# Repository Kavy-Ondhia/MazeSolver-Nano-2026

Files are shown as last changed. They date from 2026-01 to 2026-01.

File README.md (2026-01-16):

<h1 align="center">MazeSolver-Nano-2026 🏎️💨</h1>

A high-performance line-following and maze-solving robot built on the Arduino Nano platform. This project utilizes PID control and magnetic encoders for precision navigation.




<div align="center">
  <table style="width:100%; border-collapse: collapse; border: none; table-layout: fixed;">
    <tr>
      <td rowspan="2" style="width: 60%; border: none; padding: 2px;">
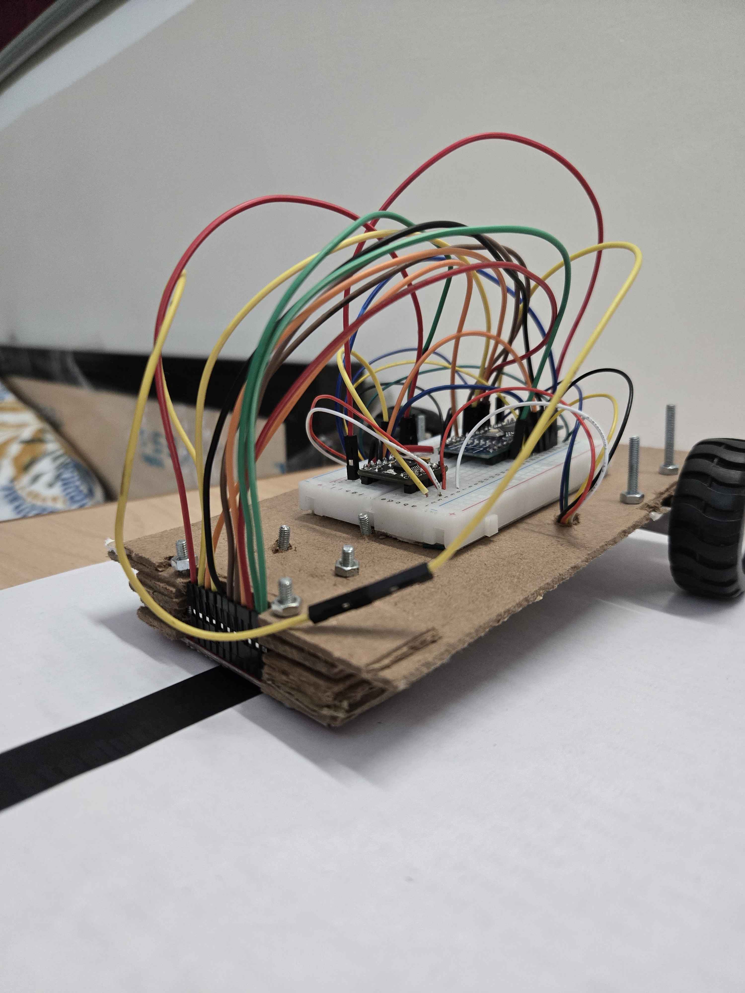
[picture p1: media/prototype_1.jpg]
Prototype Side View
        
      </td>
      <td style="width: 40%; border: none; padding: 2px;">
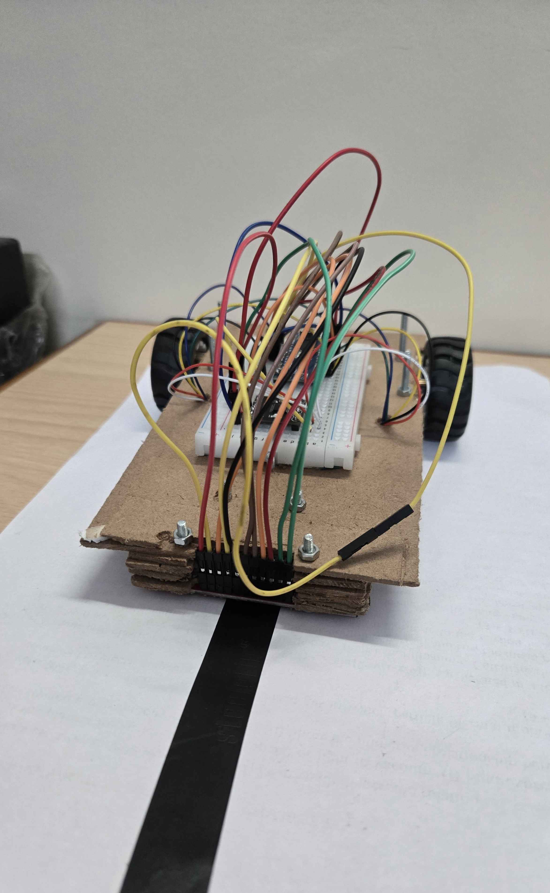
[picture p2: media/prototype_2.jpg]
Prototype Front View
        
      </td>
    </tr>
    <tr>
      <td style="border: none; padding: 2px;">
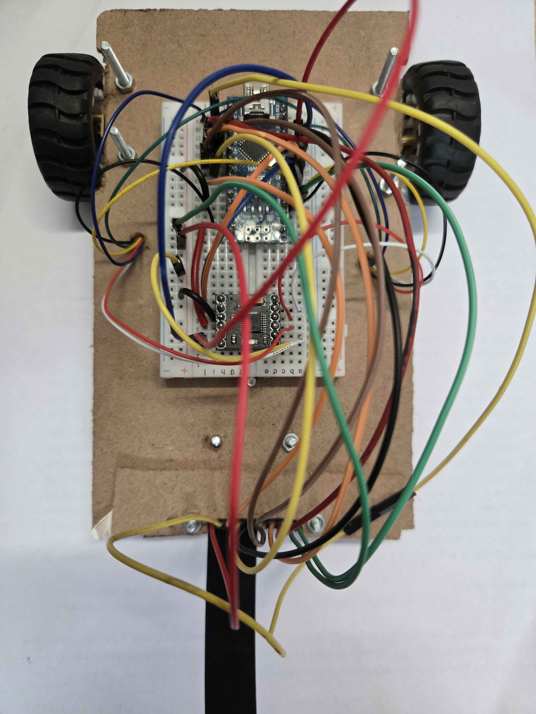
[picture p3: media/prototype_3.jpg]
Prototype Top View
        
      </td>
    </tr>
  </table>
</div>

## 🛠 Prototyping & PCB Manufacturing Phase
The project has moved from theoretical design to **active hardware-in-the-loop (HIL) testing**. I am currently validating a breadboard prototype to finalize signal routing and power stability for the custom PCB fabrication.

### **Current Progress:**
* **Prototype Controller:** Arduino Nano (ATmega328P) using a logic-stable common ground architecture.
* **Dual Motor Drive:** Integrated the **DRV8833 Dual H-Bridge** for the prototype phase, utilizing PWM-direct control to manage motor velocity and direction.
* **Sensor Integration:** Successfully calibrated a **QTR-8RC 8-channel array**. Pin mapping has been optimized (A0–A5, D7, D13) to prevent conflicts with motor PWM timers.
* **Precise Navigation:** Magnetic encoders are mapped to **Hardware Interrupt pins (D2, D3)** to ensure zero-loss pulse counting for PID speed control and distance tracking.

### **PCB Design Priorities:**
* **Signal Integrity:** Separating high-current motor traces from sensitive Encoder and Sensor signal lines to reduce Electromagnetic Interference (EMI).
* **Power Rail Optimization:** Implementing a **Buck Converter** to efficiently step down LiPo battery voltage for the logic circuit, significantly reducing heat compared to linear regulators.
* **Modular Footprint:** The PCB layout is being designed with a modular header to support both **DRV8833** and **TB6612FNG** driver footprints for testing flexibility.

## 👥 Development Team
* **Kavy Ondhia** ([@Kavy-Ondhia](https://github.com/Kavy-Ondhia))  
  *Lead Engineer — Firmware Architecture, Logic, & Hardware V2 (KiCad)*
  
* **Karunya Jajoo** ([@karunya-jajoo](https://github.com/karunya-jajoo))  
  *Contributor — Initial Hardware Concept & V1 Schematic*

## 🛠 Hardware Specifications

| Component | Purpose | Datasheet/Reference |
| :--- | :--- | :--- |
| **Arduino Nano** | Main Controller | [Official Manual](https://docs.arduino.cc/resources/datasheets/A000005-datasheet.pdf) |
| **TB6612FNG** | Motor Driver | [Toshiba Datasheet](https://www.sparkfun.com/datasheets/Robotics/TB6612FNG.pdf) |
| **N20 Motors** | 6V 200RPM w/ Encoders | [Technical Specs](https://www.handsontec.com/dataspecs/motor/N20-Motor.pdf) |
| **QTR-8RC** | IR Sensor Array | [Pololu Documentation](https://www.pololu.com/docs/0J12) |
| **SSD1306 OLED** | Debugging Display | [Adafruit Datasheet](https://cdn-shop.adafruit.com/datasheets/SSD1306.pdf) |
| **HC-05** | Bluetooth Module | [HC-05 Datasheet](https://components101.com/sites/default/files/component_datasheet/HC-05-Datasheet.pdf) |
| **LM2596 Buck** | 5V Regulation | [TI Datasheet](https://www.ti.com/lit/ds/symlink/lm2596.pdf) |

## 🔌 Proposed Pin Mapping (Nano)
*This table serves as the "contract" for the schematic design.*

| Standard Pin | KiCad Symbol Label | Component | Function | Status vs. Old |
| :--- | :--- | :--- | :--- | :--- |
| **D2** | D2 (Right Pin 11) | Encoder Left | Interrupt A (Phase A) | UNCHANGED |
| **D11** | D11 (Right Pin 2) | Encoder Left | Phase B (Dir Tracking) | UNCHANGED |
| **D3** | D3 (Right Pin 10) | Encoder Right | Interrupt B (Phase A) | UNCHANGED |
| **D12** | D12 (Right Pin 1) | Encoder Right | Phase B (Dir Tracking) | UNCHANGED |
| **D4** | D4 (Right Pin 9) | TB6612 (BIN1) | Right Motor Dir | UNCHANGED |
| **D5** | D5 (Right Pin 8) | TB6612 (BIN2) | Right Motor Dir | UNCHANGED |
| **D7** | D7 (Right Pin 6) | TB6612 (AIN1) | Left Motor Dir | UNCHANGED |
| **D8** | D8 (Right Pin 5) | TB6612 (AIN2) | Left Motor Dir | UNCHANGED |
| **D9** | D9 (Right Pin 4) | TB6612 (PWMA) | Left Motor Speed (PWM) | UNCHANGED |
| **D10** | D10 (Right Pin 3) | TB6612 (PWMB) | Right Motor Speed (PWM) | UNCHANGED |
| **A0** | D14 (Left Pin 4) | QTR-8RC Pin 1 | IR Reflectance | UNCHANGED |
| **A1** | D15 (Left Pin 5) | QTR-8RC Pin 2 | IR Reflectance | UNCHANGED |
| **A2** | D16 (Left Pin 6) | QTR-8RC Pin 3 | IR Reflectance | UNCHANGED |
| **A3** | D17 (Left Pin 7) | QTR-8RC Pin 4 | IR Reflectance | UNCHANGED |
| **D6** | D6 (Right Pin 7) | QTR-8RC Pin 5 | IR Reflectance | UNCHANGED |
| **A4** | D18 (Left Pin 8) | QTR-8RC Pin 6 | IR Reflectance | **MOVED** (From D13) |
| **A5** | D19 (Left Pin 9) | QTR-8RC Pin 7 | IR Reflectance | **MOVED** (From A6) |
| **D13** | D13 (Left Pin 1) | QTR-8RC Pin 8 | IR Reflectance | **MOVED** (From A7) |
| **D0** | D0 (RX) | NOT USED | Leave Empty for Uploads | **REMOVED** (Finish LED) |
| **A6 / A7** | A6 / A7 | NOT USED | Hardware Input Only | **VOID** |

### ⚠️ Critical Hardware Notes
* **A6/A7 Pins:** These pins on the Nano are **Analog Input Only**. They cannot be used for the QTR-8RC or Motor Standby because they cannot function as Digital Outputs.
* **QTR-8RC Version:** This project uses the **RC (Digital)** version of the sensor. Pins are toggled as outputs to charge the onboard capacitor, then read as inputs to measure discharge time.
* **USB Uploading:** Digital Pin **D0 (RX)** is left disconnected to prevent serial communication conflicts during code uploading.

## 🛠 Hardware Design

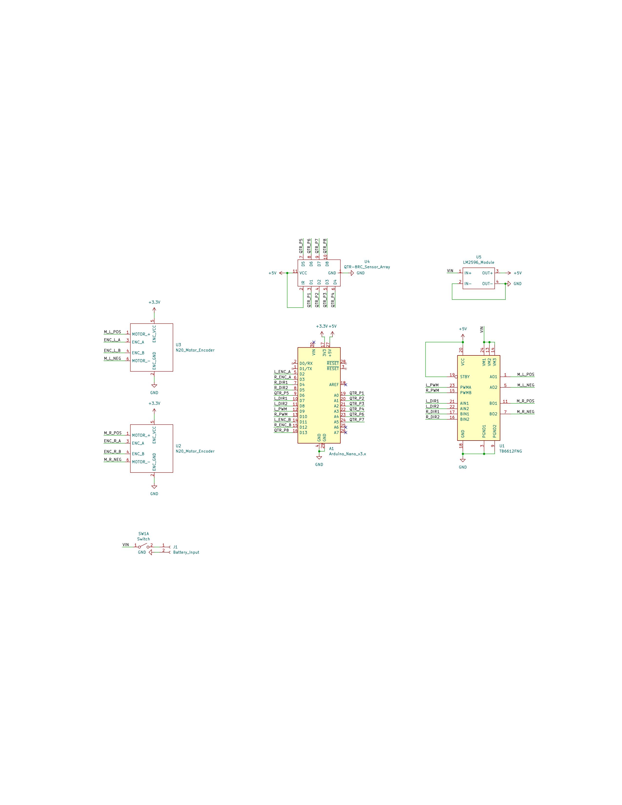
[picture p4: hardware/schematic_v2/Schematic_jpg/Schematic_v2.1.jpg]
Robot Schematic

[Download PDF Version](hardware/schematic_v2/Schematic_pdf/Schematic_v2.1.pdf)

## 🧠 Software Logic & Path Optimization

The robot's intelligence is divided into three layers: **Perception**, **Control**, and **Strategy**.

### 1. Perception & Control (PID)
* **The Error:** Using the QTR-8RC, we calculate the robot's position relative to the center (3500). 
    * $Error = 3500 - \text{Current Reading}$
* **PID Math:** We use Proportional (Muscle) and Derivative (Brakes) logic to calculate correction.
    * `Correction = (Kp * error) + (Kd * (error - lastError))`
    * `LeftSpeed = Base + Correction` | `RightSpeed = Base - Correction`

### 2. The Discovery Phase (Dry Run)
The robot uses a **Preferential Wall-Following Rule** (Straight > Left > Right). 
* **The Log:** Every move is recorded in a memory array.
* **Encoder Mapping:** Encoders track distance in millimeters to ensure precise turns and junction detection.

### 3. Path Optimization (The "Aha!" Moment)
The robot simplifies its recorded path by removing dead ends (represented as 'B' for Back).
* **Logic:** `Left -> Back -> Left` is simplified to `Straight`.
* **Optimization Example:** `L -> B -> L` becomes `S`. This "shrinks" the journey for the final run.

### 4. Advanced Mapping & Exploration
To cover the entire map, the robot utilizes a coordinate-based Node system:
```cpp
struct Node {
  long x;           // X coordinate from encoders
  long y;           // Y coordinate from encoders
  bool visited[3];  // [Left, Straight, Right]
  int parentNode;   // Back-tracking reference
};
```

## 📸 Component Gallery
<p align="center">
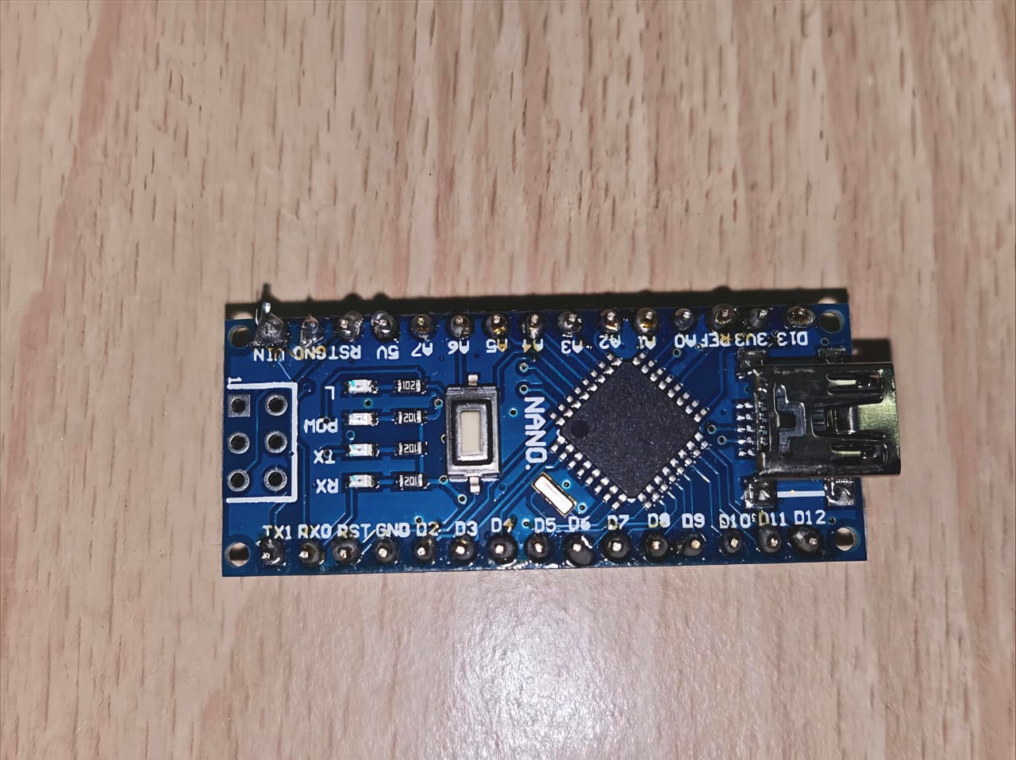
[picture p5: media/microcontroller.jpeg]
  
</p>
<p align="center">
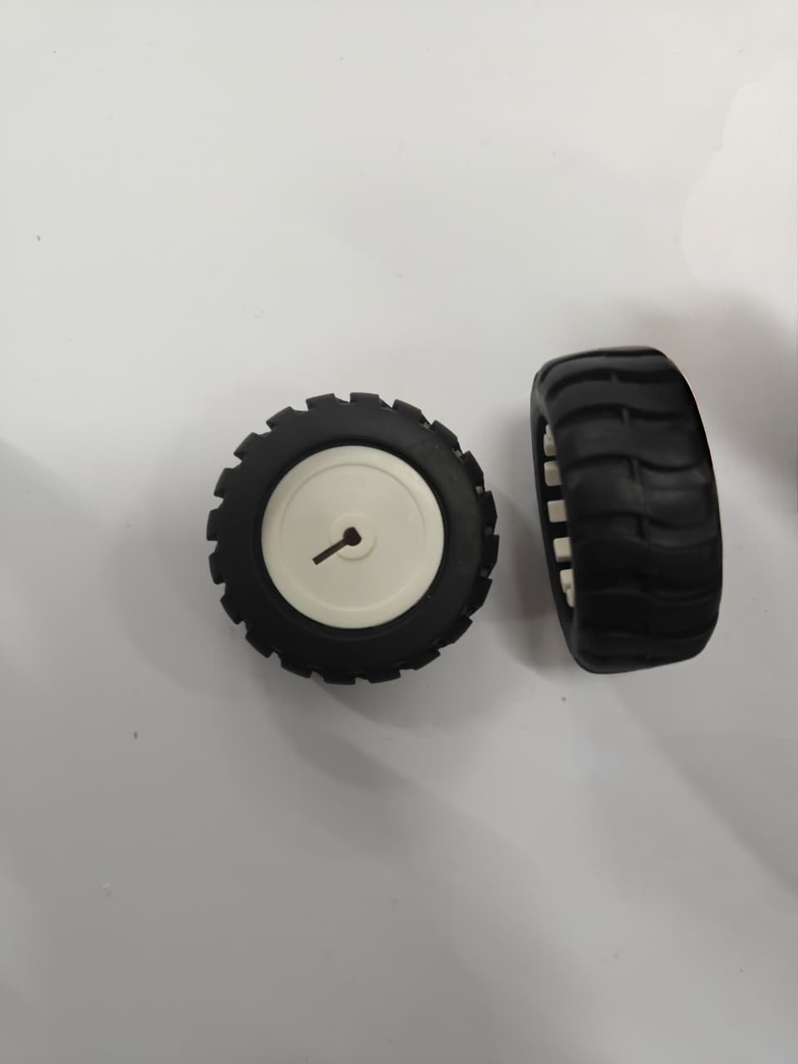
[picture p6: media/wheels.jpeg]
  
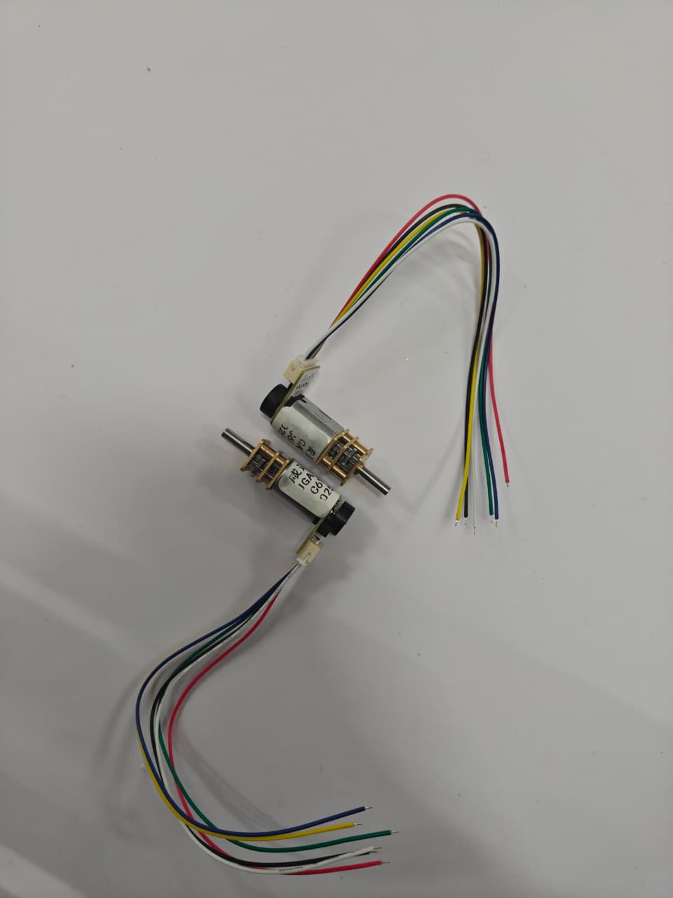
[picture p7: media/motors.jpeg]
  
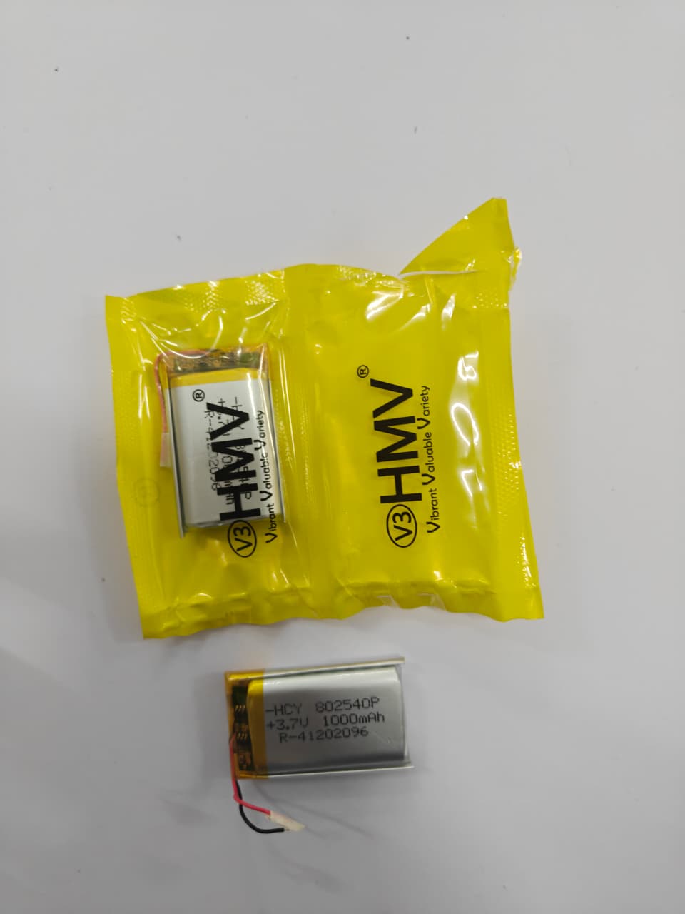
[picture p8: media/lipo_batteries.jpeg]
  
</p>
<p align="center">
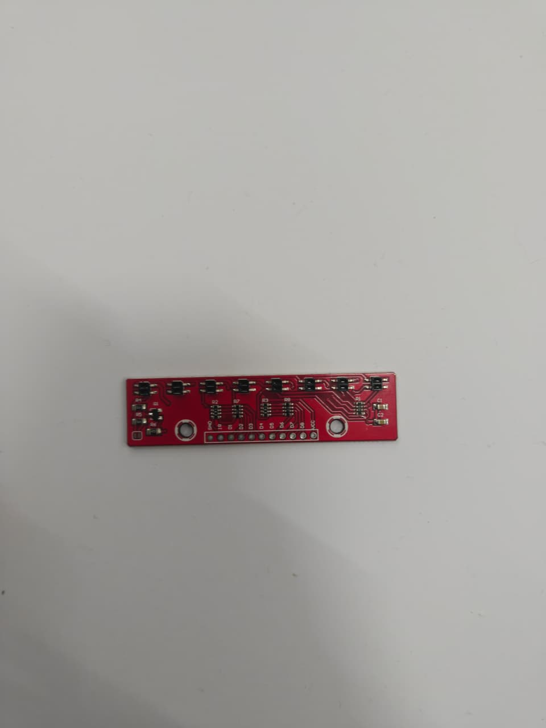
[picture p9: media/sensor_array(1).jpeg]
  
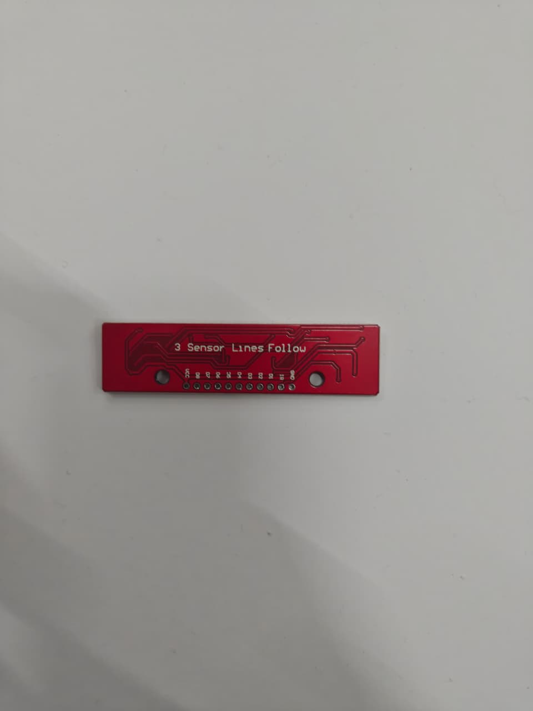
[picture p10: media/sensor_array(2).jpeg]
  
</p>

## 📂 Project Structure
* `/src`: Final Arduino (.ino) and configuration (.h) files.
* `/hardware`: Schematic diagrams and PCB layouts (In Progress).
* `/media`: Component photos and project progress shots.

---
*Created by [Kavy Ondhia](https://github.com/Kavy-Ondhia)*

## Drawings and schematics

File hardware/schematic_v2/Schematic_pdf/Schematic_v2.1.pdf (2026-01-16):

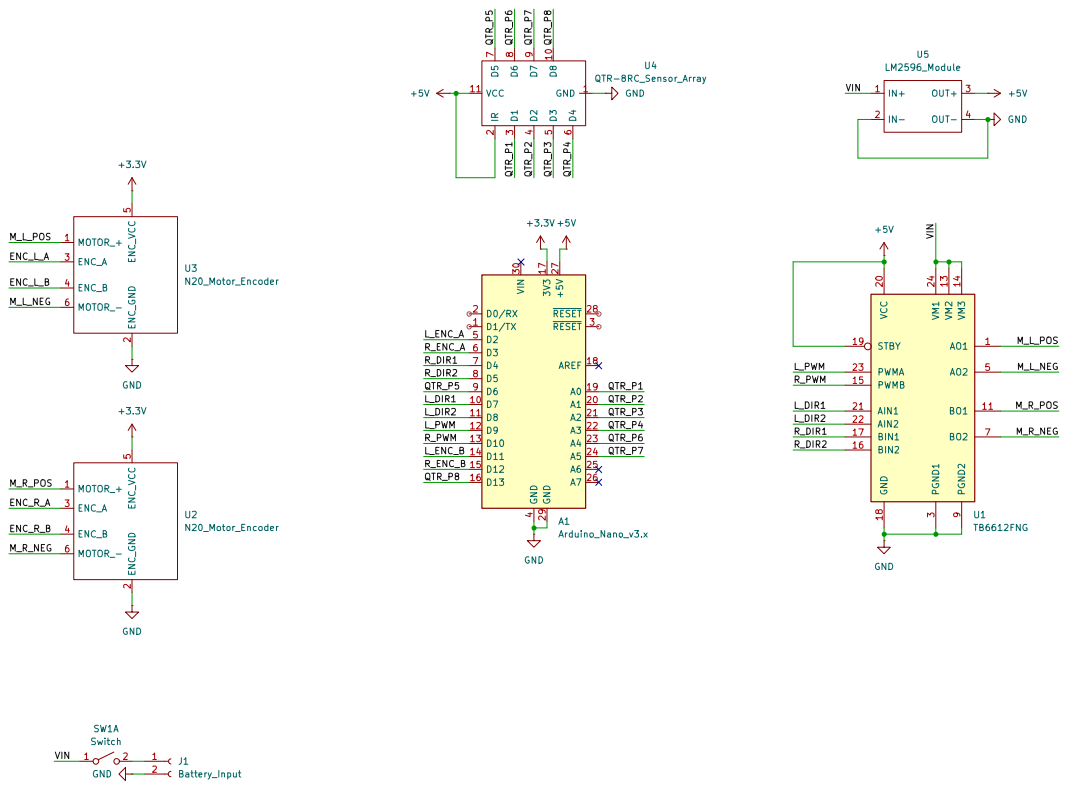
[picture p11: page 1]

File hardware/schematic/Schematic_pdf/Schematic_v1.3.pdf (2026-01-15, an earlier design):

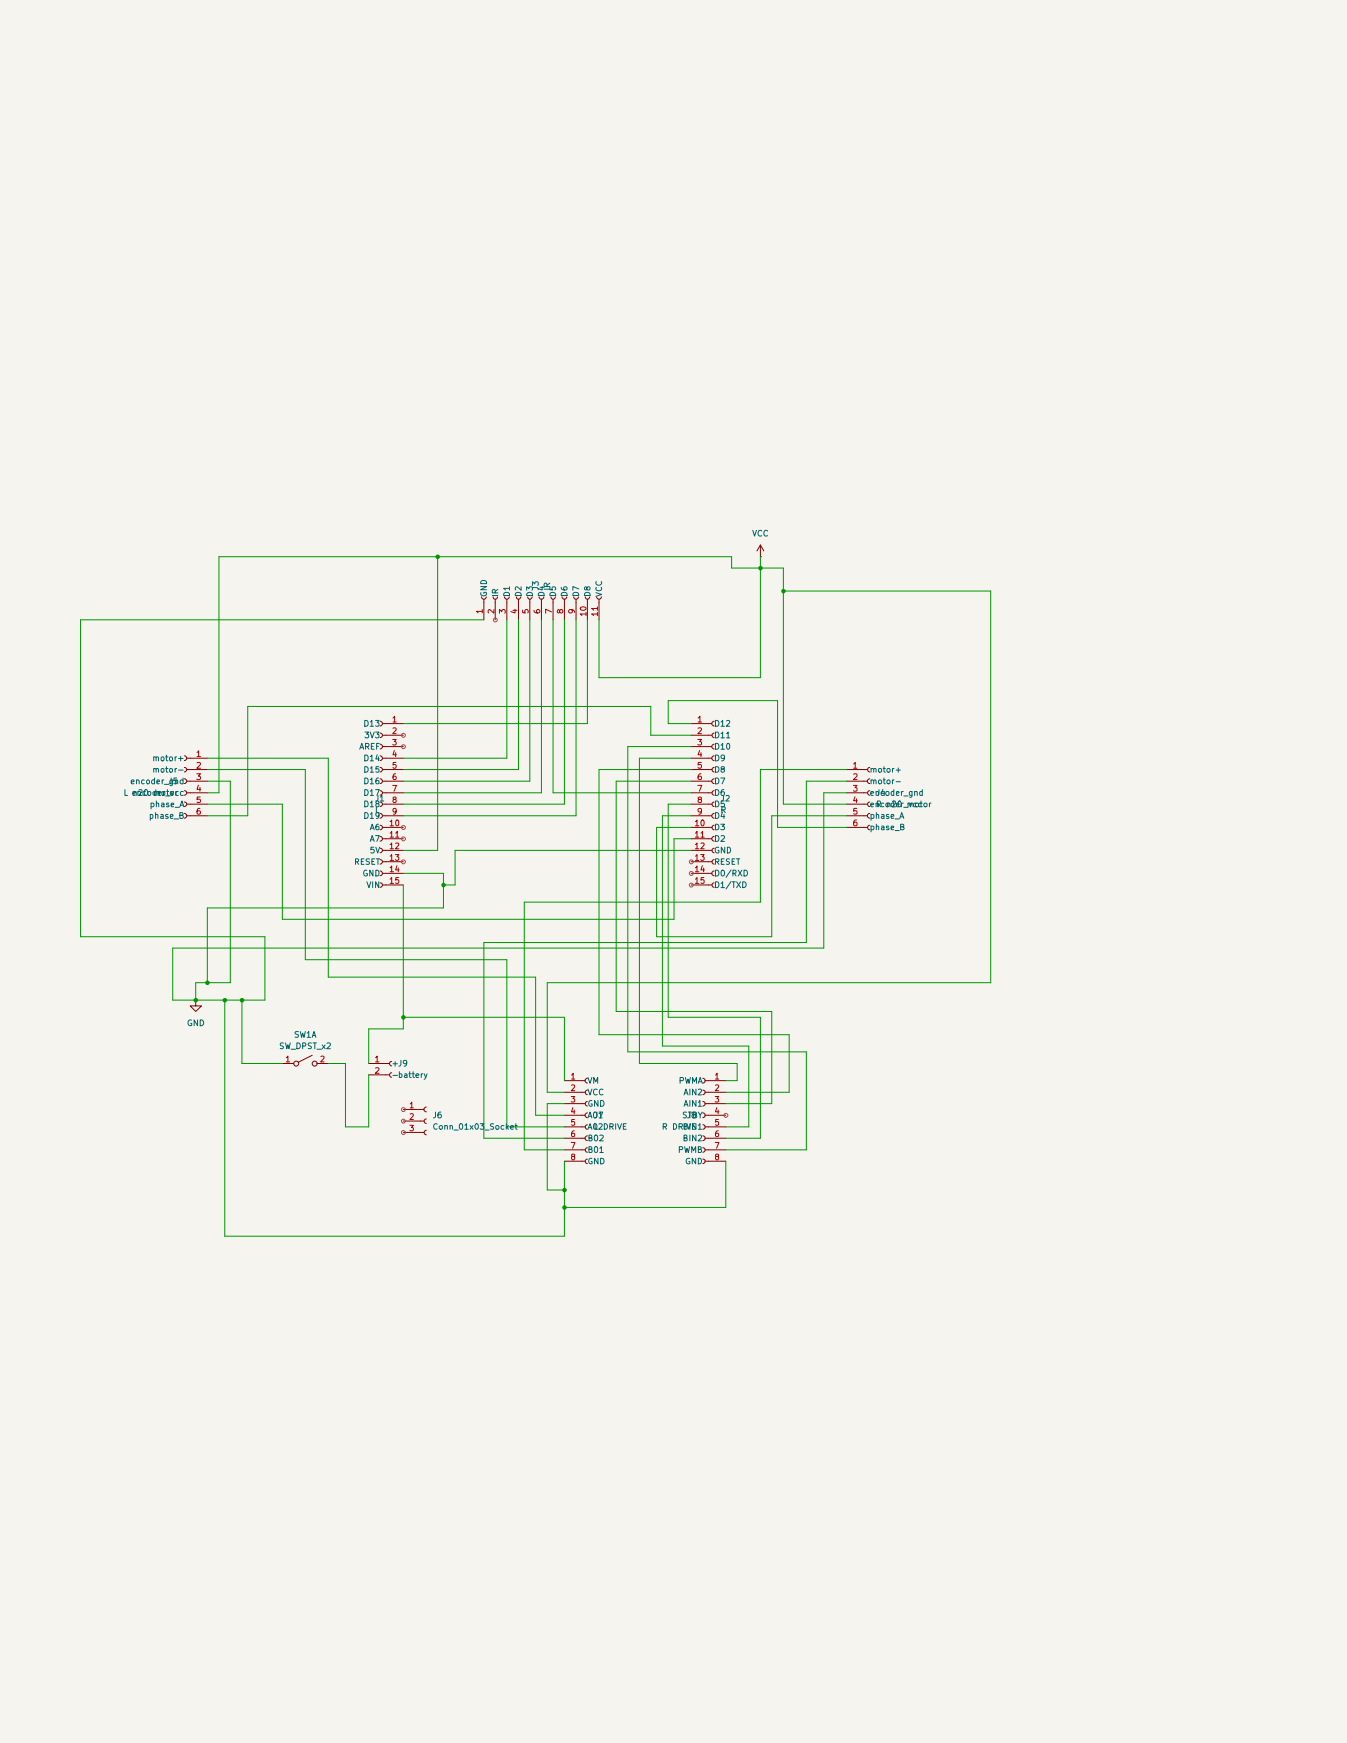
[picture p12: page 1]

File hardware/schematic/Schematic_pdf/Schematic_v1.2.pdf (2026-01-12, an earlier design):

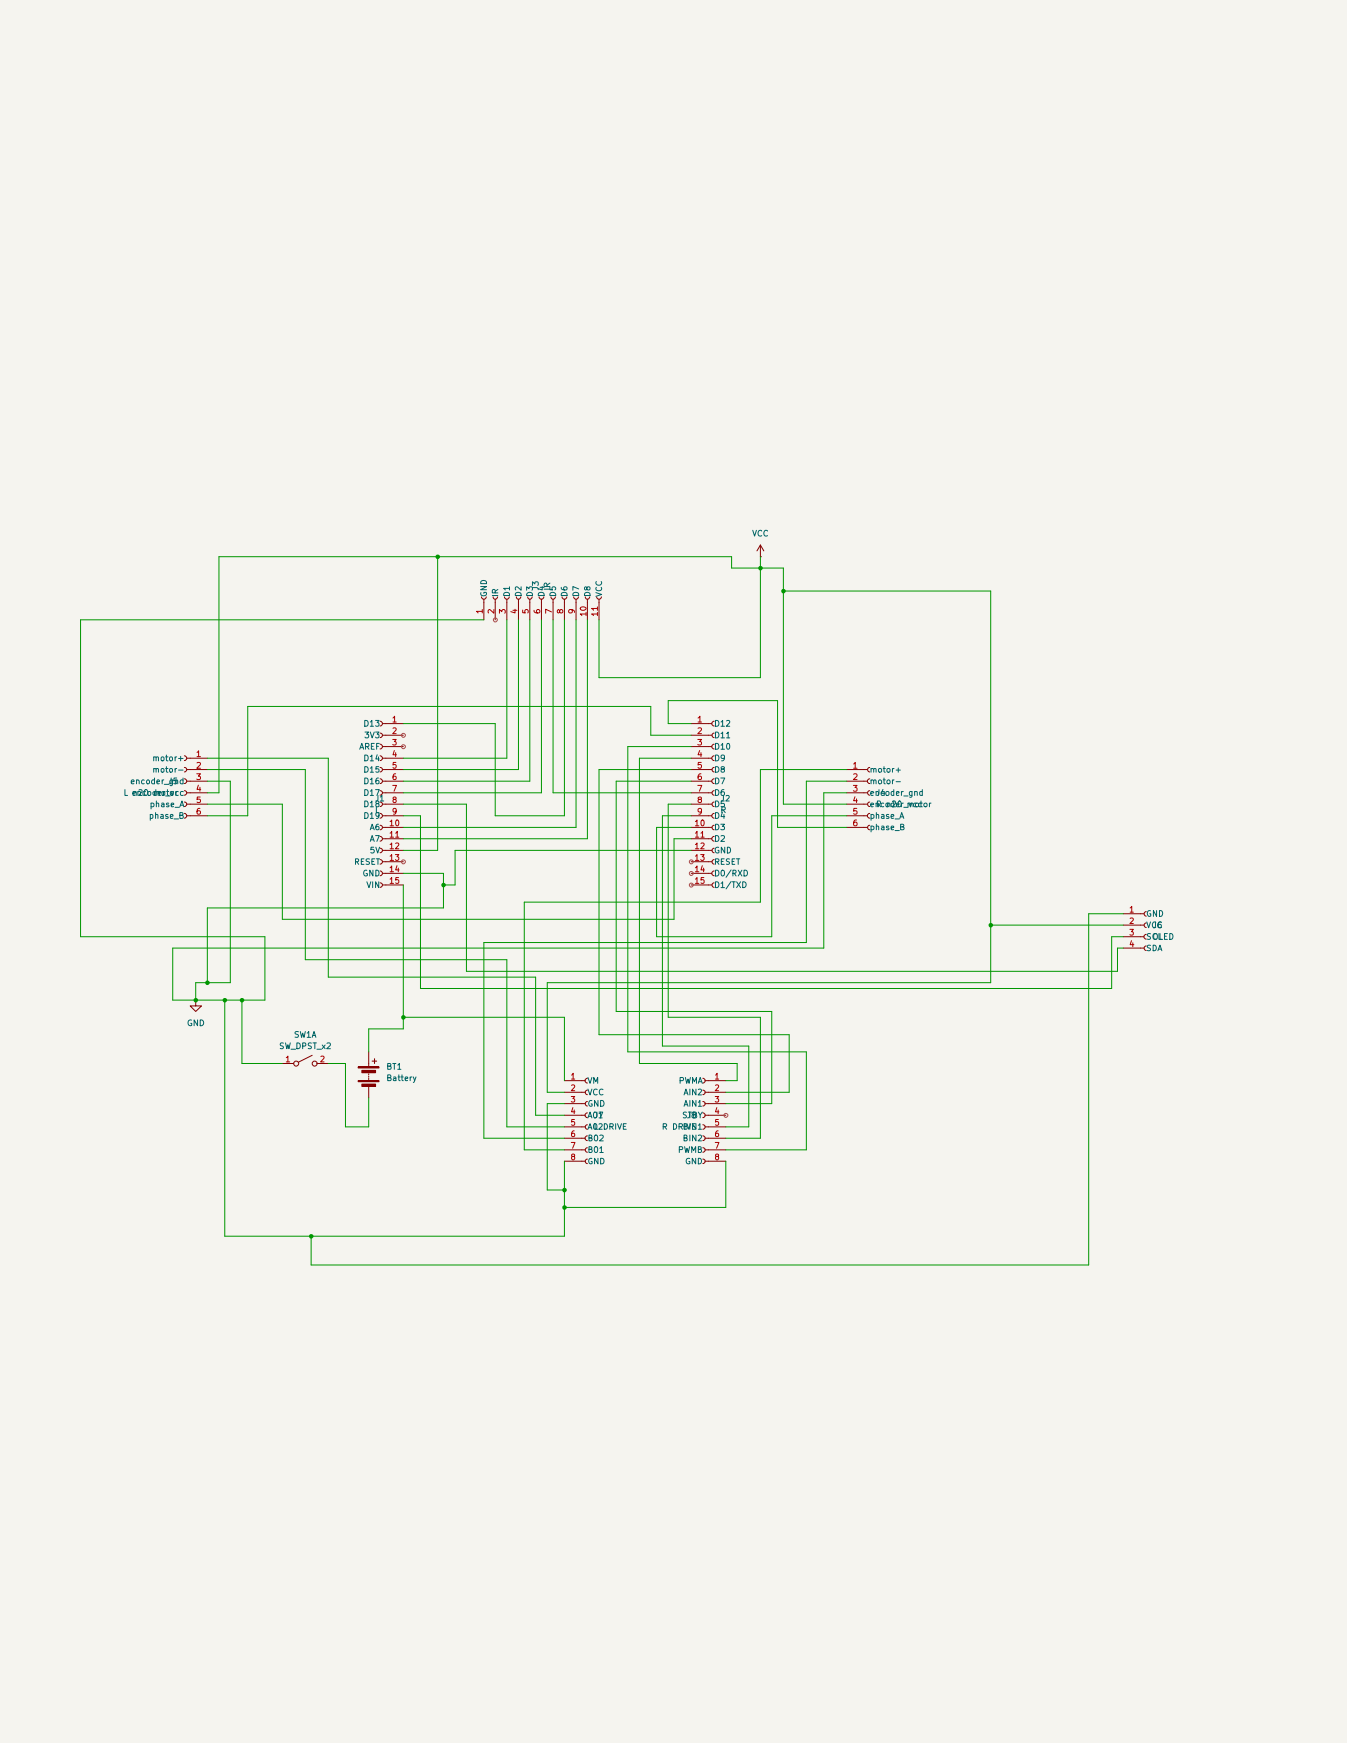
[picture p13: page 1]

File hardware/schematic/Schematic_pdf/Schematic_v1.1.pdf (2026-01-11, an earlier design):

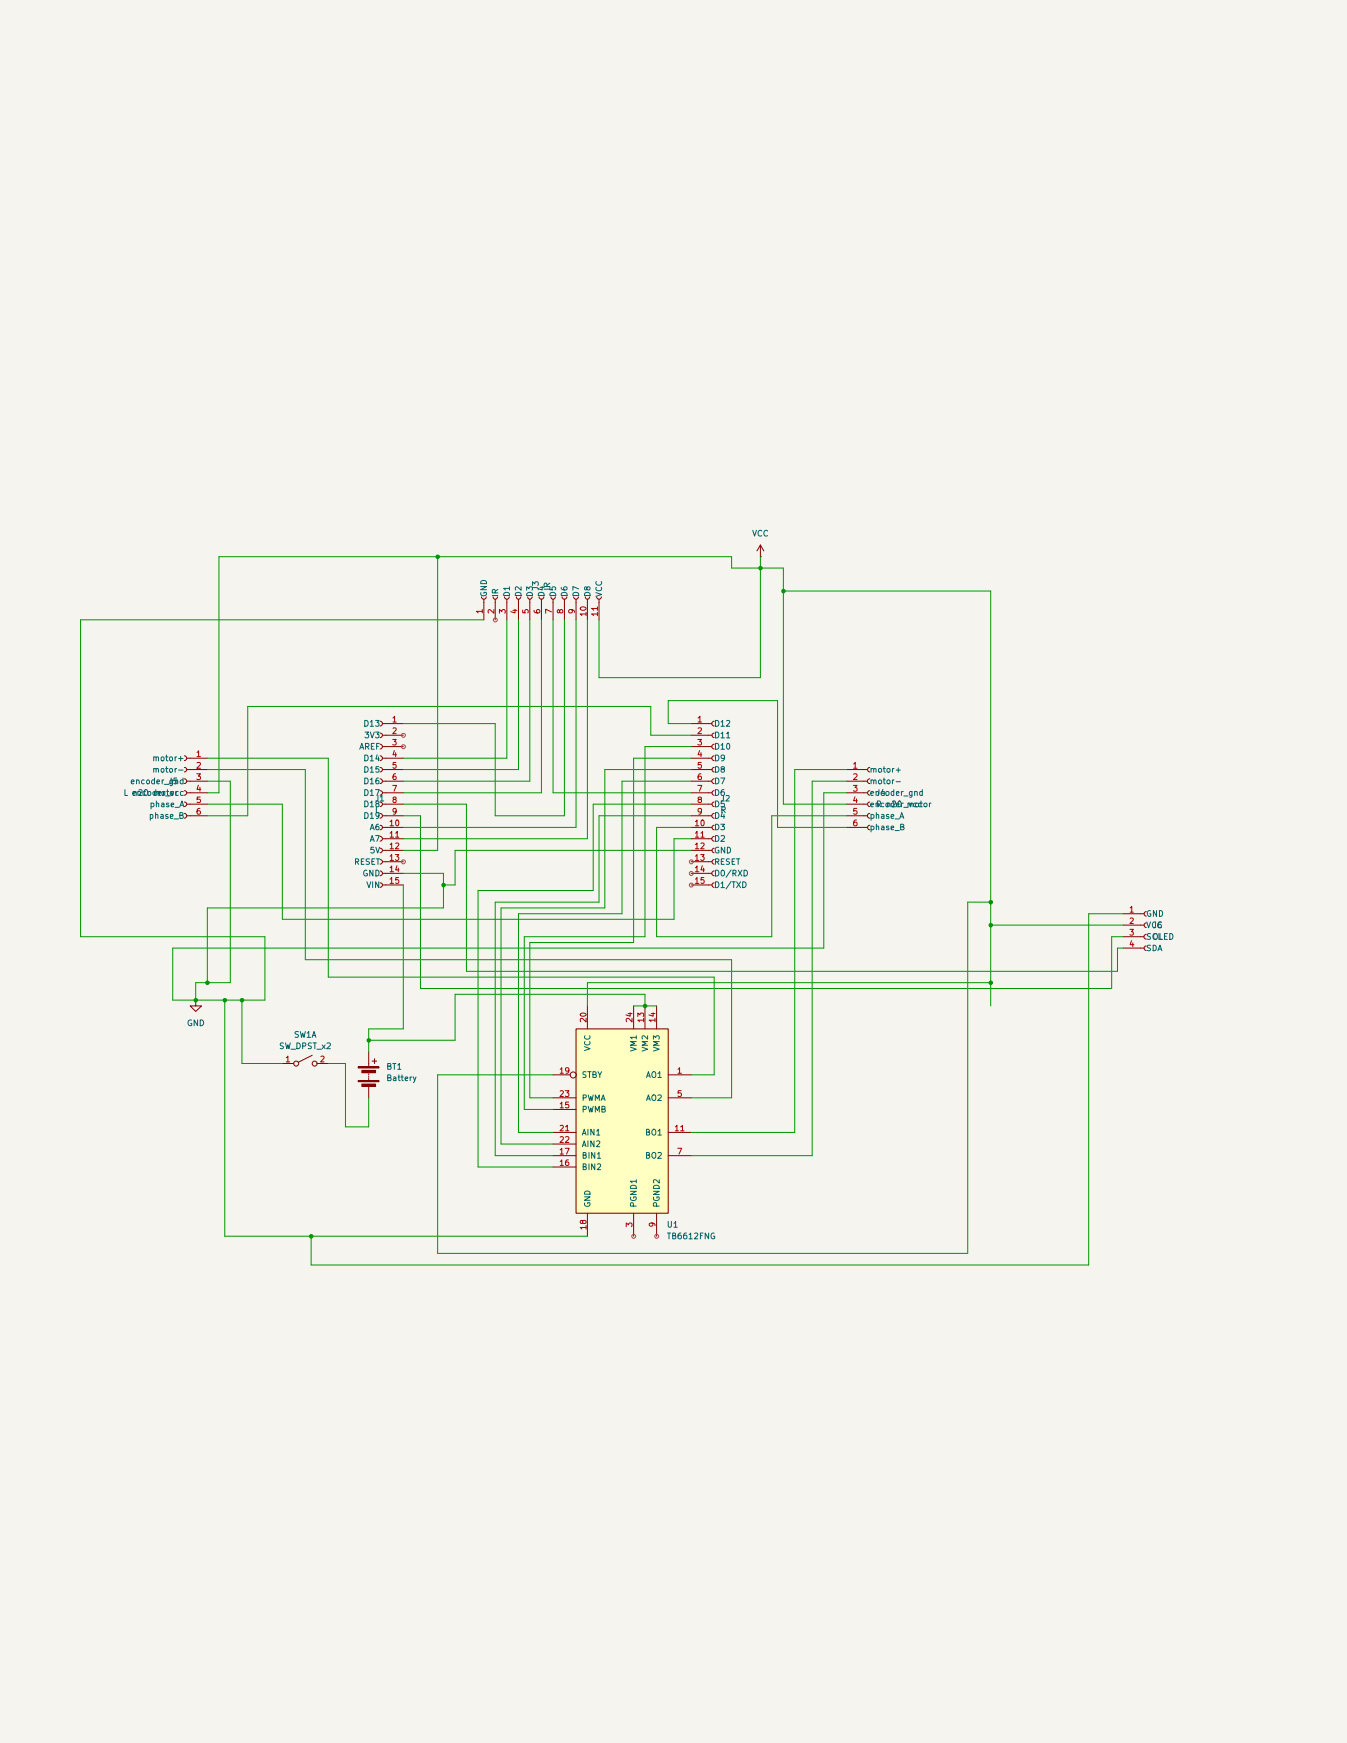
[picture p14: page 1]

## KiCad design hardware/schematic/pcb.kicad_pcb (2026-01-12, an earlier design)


Board: 2 copper layers, 3 parts (0 on the bottom side), 10 nets, no tracks yet.

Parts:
J1: L; PinSocket_1x15_P2.54mm_Horizontal
J2: R; PinSocket_1x15_P2.54mm_Horizontal
J3: IR; PinSocket_1x15_P2.54mm_Horizontal

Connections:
unnamed: J1.12 (5V), J3.11 (VCC)
unnamed: J1.10 (A6), J3.10 (D8)
unnamed: J2.11 (D2), J3.3 (D1)
unnamed: J2.9 (D4), J3.4 (D2)
unnamed: J2.6 (D7), J3.5 (D3)
unnamed: J2.5 (D8), J3.6 (D4)
unnamed: J2.3 (D10), J3.7 (D5)
unnamed: J2.2 (D11), J3.8 (D6)
unnamed: J2.1 (D12), J3.9 (D7)
unnamed: J2.12 (GND), J3.1 (GND)

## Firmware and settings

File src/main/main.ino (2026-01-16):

#include <QTRSensors.h>
#include "Configuration.h"

QTRSensors qtr;
uint16_t sensorValues[SENSOR_COUNT];

// PID Variables
int lastError = 0;
int baseSpeed = 120; // Start slower for the prototype
int maxSpeed = 200;  // Limit power to protect the DRV8833

void setup() {
  Serial.begin(9600);
  
  // 1. Initialize Hardware
  setupMotors();
  setupEncoders();
  
  // 2. Initialize Sensors (A0-A5, D6, D13)
  qtr.setTypeRC();
  const uint8_t pins[] = SENSOR_PINS; 
  qtr.setSensorPins(pins, SENSOR_COUNT);
  
  // 3. Calibration (Robot spins to "see" the line)
  calibrateRobot();
  
  Serial.println("Ready to follow line!");
}

void loop() {
  // 1. Get position (0 to 7000)
  uint16_t position = qtr.readLineBlack(sensorValues);

  // 2. Safety Check: If robot is completely off the line
  // If all middle sensors see white, use last known error to find the line
  if (sensorValues[2] < 150 && sensorValues[3] < 150 && sensorValues[4] < 150 && sensorValues[5] < 150) {
    if (lastError > 0) driveMotors(baseSpeed, -baseSpeed); // Sharp right recovery
    else driveMotors(-baseSpeed, baseSpeed);              // Sharp left recovery
    return;
  }

  // 3. PID Calculation
  int error = (int)position - 3500;
  
  // Standard PID formula
  int correction = (Kp * error) + (Kd * (error - lastError));
  lastError = error;

  // 4. Calculate Motor Speeds
  int leftMotorSpeed = baseSpeed + correction;
  int rightMotorSpeed = baseSpeed - correction;

  // 5. Constrain speeds to PWM limits (0-255)
  leftMotorSpeed = constrain(leftMotorSpeed, -maxSpeed, maxSpeed);
  rightMotorSpeed = constrain(rightMotorSpeed, -maxSpeed, maxSpeed);

  // 6. Execution
  driveMotors(leftMotorSpeed, rightMotorSpeed);
}

// --- HARDWARE CONTROL FUNCTIONS ---

void driveMotors(int left, int right) {
  // LEFT MOTOR: DRV8833 Logic
  if (left >= 0) {
    analogWrite(MOTOR_L_IN1, left);
    digitalWrite(MOTOR_L_IN2, LOW);
  } else {
    digitalWrite(MOTOR_L_IN1, LOW);
    analogWrite(MOTOR_L_IN2, abs(left));
  }

  // RIGHT MOTOR: DRV8833 Logic
  if (right >= 0) {
    analogWrite(MOTOR_R_IN1, right);
    digitalWrite(MOTOR_R_IN2, LOW);
  } else {
    digitalWrite(MOTOR_R_IN1, LOW);
    analogWrite(MOTOR_R_IN2, abs(right));
  }
}

void calibrateRobot() {
  Serial.println("Calibrating... Spinning...");
  digitalWrite(LED_BUILTIN, HIGH);

  for (uint16_t i = 0; i < 200; i++) {
    // Slowly spin in place to pass sensors over the line
    driveMotors(100, -100); 
    qtr.calibrate();
    delay(10);
  }
  
  driveMotors(0, 0); 
  digitalWrite(LED_BUILTIN, LOW);
  Serial.println("Calibration Done.");
}

void setupMotors() {
  pinMode(MOTOR_L_IN1, OUTPUT);
  pinMode(MOTOR_L_IN2, OUTPUT);
  pinMode(MOTOR_R_IN1, OUTPUT);
  pinMode(MOTOR_R_IN2, OUTPUT);
  // DRV8833 Sleep/Enable pin if you have one connected
  // pinMode(MOTOR_STBY, OUTPUT);
  // digitalWrite(MOTOR_STBY, HIGH);
}

void setupEncoders() {
  pinMode(ENCODER_L_A, INPUT);
  pinMode(ENCODER_L_B, INPUT);
  pinMode(ENCODER_R_A, INPUT);
  pinMode(ENCODER_R_B, INPUT);
}

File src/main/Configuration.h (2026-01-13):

#ifndef CONFIGURATION_H
#define CONFIGURATION_H

// --- MOTOR PINS ---
#define MOTOR_L_PWM 9
#define MOTOR_L_IN1 7
#define MOTOR_L_IN2 8

#define MOTOR_R_PWM 10
#define MOTOR_R_IN1 4
#define MOTOR_R_IN2 5

#define MOTOR_STBY 6 // Tied to 5V or D6 depending on Karunya's final trace

// --- ENCODER PINS ---
#define ENCODER_L_A 2   // Interrupt
#define ENCODER_L_B 11  // Direction
#define ENCODER_R_A 3   // Interrupt
#define ENCODER_R_B 12  // Direction

// --- SENSOR SETTINGS ---
#define SENSOR_COUNT 8
// Pins based on your table: A0, A1, A2, A3, D6, A4, A5, D13
#define SENSOR_PINS {A0, A1, A2, A3, 6, A4, A5, 13}
#define CALIBRATION_SPEED 100 

// --- PID CONSTANTS ---
float Kp = 0.5;
float Kd = 1.0;
float Ki = 0.0;

#endif

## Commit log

2026-01-08 Add .gitignore for Arduino and build files
2026-01-09 feat: setup motor pins and QTR calibration logic
    [Configuration.h]
2026-01-09 chore: critical fix for file content swap
    [Configuration.h]
2026-01-09 docs: fix broken links and add pin mapping table
2026-01-09 docs: add high-quality photos of hardware components
    [Configuration.h]
2026-01-09 docs: add path optimization and PID logic
2026-01-09 feat: initial KiCad project setup with Nano symbol
    [schematic.kicad_pcb, schematic.kicad_sch]
2026-01-10 docs: update pin mapping table to match KiCad labels
2026-01-10 Update: Finalized pin map to support 8 sensors + OLED by moving QTR pins to D0/D1
2026-01-10 Update: Fixed Pin Mapping
2026-01-11 Update pin mapping: Moved IR sensors to free up I2C for OLED
2026-01-11 Hardware: Full schematic overhaul
    [schematic.kicad_pcb, schematic.kicad_sch]
2026-01-11 Hardware: Schematic added
2026-01-12 Hardware: Minor changes in schematic
    [pcb.kicad_pcb, pcb.kicad_sch, schematic.kicad_pcb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]
2026-01-12 Hardware: Changed readme file and added schematic pdf and photo
2026-01-13 Hardware: Minor schematic changes
    [pcb.kicad_sch]
2026-01-13 Software: Changed files according to new pin mapping
    [Configuration.h]
2026-01-14 Software: Implemented sensor logic
2026-01-14 Added images of Arduino Nano
2026-01-15 Hardware: Changed schematic according to new pin mapping
    [pcb.kicad_sch]
2026-01-16 Added prototype images
2026-01-16 refactor: initialize Hardware V2 and update project ownership
    - Migrated hardware design to KiCad for V2 schematic.
    - Assumed lead for Hardware Design & PCB Layout.
    - Updated README to reflect current development team roles.
2026-01-16 Added new v2.1 schematic
    [MazeSolver_Nano_V2.kicad_pcb, MazeSolver_Nano_V2.kicad_sch]
